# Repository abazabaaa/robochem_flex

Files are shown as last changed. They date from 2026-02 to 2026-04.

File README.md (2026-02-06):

NRG Logo

# Robochem-Flex

This repository bundles the **software, device files, and example data** for the  
**Robochem-Flex** platform: a modular self-driving laboratory framework.  

---

## 🔎 Repository Structure

- **Control Software**  
  Streamlit application and supporting backend code for configuring and running optimisation campaigns.

- **Devices**  
  Hardware resources such as CAD models, firmware, and PCB designs for the actuators and sensors used on the platform.

- **Examples**  
  Sample configuration files demonstrating how to set up a campaign and define stock solutions or vial layouts.

Each directory contains more detailed documentation specific to its contents.  
To run the platform optimization code, please refer to the README.md file within the Control Software folder.

---

## 🧑‍🔬 Authorship & Credits

The contents of this repository have been developed by:  

- **Dr. Simone Pilon** – University of Amsterdam, Noël Research Group
- **Ir. Elia Savino** – University of Amsterdam, Noël Research Group 
- **Dr. Oliver M. Bayley** – University of Amsterdam, Noël Research Group

for full credits on the project, please see the [accompanying publication](https://chemrxiv.org/doi/10.26434/chemrxiv-2025-73xqf).

If you use any part of this repository, please cite the accompanying publication.

---

## ⚖️ Licensing

The contents of this repository are licensed under the Apache License, Version 2.0.
For more information, consult the NOTICE and LICENSE files.

Copyright 2025 [Noël Research Group](https://www.noelresearchgroup.com).

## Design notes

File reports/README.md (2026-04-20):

# Reports Index

This directory contains ten cross-cutting reports that dissect the `robochem_flex` self-driving-lab codebase from the wire protocol up to the Bayesian-optimisation loop and the analytics feedback path. Each report is self-contained but cross-references the others; together they answer the question "how does this code control a robot, and how does it close the loop with machine learning?". File/line citations point into `Control Software/OmniPlatypus/…`, `Control Software/backend/…`, `Control Software/Lamas/…`, and `Devices/*/Firmware/*.ino`. Start here, then read in one of the two orders below. For a single-document synthesis, see `../REPO_MAP.md`.

## Contents

| # | Title | Purpose |
|---|---|---|
| 01 | Hardware Communication Layer | Dissects `BaseDevice`, the `ArduinoDevice`/`ModbusDevice`/`SocketDevice` transports, and the `ArrayDevice`/`ProxyDevice` pattern that lets many sub-units share one serial port. |
| 02 | Platform & Device Configuration | Explains `platform_config.json`, `Platform.build()`, `known_devices.json` serial-ID discovery, and `SampleHolder` vial-rack geometry. |
| 03 | Unit Task to Wire Trace | Follows `PumpVolume` and `SetLightSourceIntensity` all the way from Python down to the literal ASCII bytes on the serial wire and the matching firmware `case` handler. |
| 04 | Experiment Orchestration Lifecycle | Documents `BaseExperiment`'s threads, five queues, `RunResult`, and the `ChemicalReaction`/`PhotochemicalReaction`/`ThermochemicalReaction` subclasses. |
| 05 | ML - Hardware Closed Loop | Traces BoTorch backends, `ToandFromMachine` tensor/recipe translation, and the queue boundary between the ML thread and the experiment thread. |
| 06 | Sample Prep & Liquid Handling | Covers `StockSolutionDF`/`VialDF`, the `GenerateComposition` linear-programming recipe solver, and the pump/sampler unit tasks. |
| 07 | Analytics & Measurement Feedback | Walks raw spectra through Alpaca, Vicuna, Guanaco, and Lama; contrasts NMR/HPLC/Raman/UV-Vis analyser classes; defines the `result_metrics`/`pass` contract. |
| 08 | End-to-End CS1 Walkthrough | A single Bayesian iteration of the `Examples/CS1` photoredox campaign on platform Perry, from Start button to refitted GP posterior. |
| 09 | Arduino Firmware Protocol Reference | Per-device variable tables, the `Sx=y`/`Rx` line protocol at 9600 baud, ACK characters, and firmware safety interlocks. |
| 10 | Safety, Errors & Recovery | Error-class taxonomy, the three-tier retry/restart policy, known gaps including the missing hardware emergency-stop. |

## Read in this order

- **To understand how the code controls a robot** (bottom-up mechanics): start with **02** (platform configuration), then **01** (the `BaseDevice` abstraction), then **09** (what the firmware actually expects on the wire), then **03** (a worked wire-trace), then **08** (it all comes together).
- **To understand the ML loop** (top-down chemistry and learning): start with **05** (the optimizer and the queue boundary), then **06** (how a tensor becomes a real slug), then **07** (how a spectrum becomes a scalar), then **04** (the orchestrator that threads the two together), then **08** (a concrete campaign iteration).

Reports 09 and 10 are reference material — consult them on demand when the other reports cite specific firmware variables or error classes.

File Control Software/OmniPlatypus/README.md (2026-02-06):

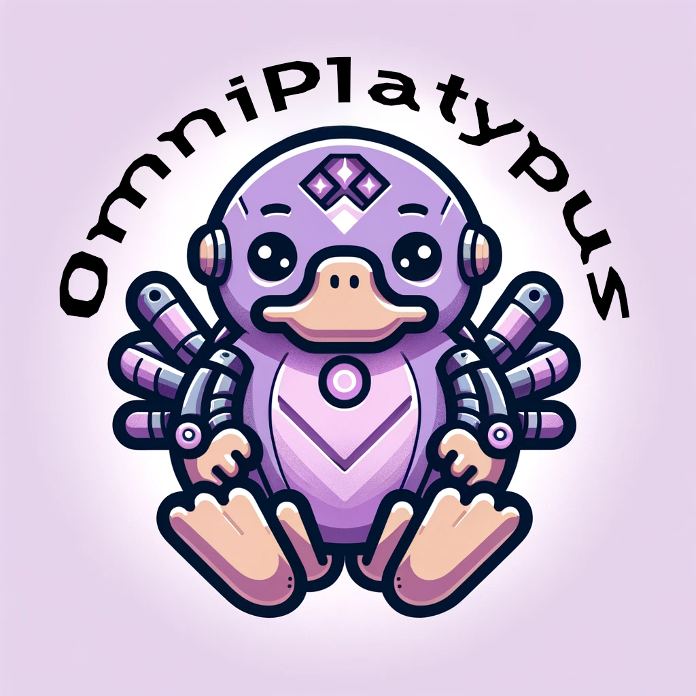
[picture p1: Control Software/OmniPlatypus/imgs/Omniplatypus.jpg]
Omniplatypus Logo
# OmniPlatypus

> ***"We're stuck with technology when what we really want is just stuff that works"***  
> — *Douglas Adams (The Salmon of Doubt) *

The **NRG's next-generation platform for Automated Chemistry**, providing a flexible, modular, and easily extendable framework to control, coordinate, and analyze complex experimental setups.

OmniPlatypus is designed for **atomic customizability**: every device, unit task, and experimental procedure can be configured, reused, or replaced independently. The platform supports seamless communication between analytical instruments, pumps, sensors, and other devices — enabling full workflow automation.

---

## Building the Package

If you’re unsure whether the local package is up to date, rebuild it manually.

From the directory containing the `setup.py` file, run:
```bash
python setup.py sdist bdist_wheel
```

Then uninstall and reinstall the package:
```bash
pip uninstall omniplatypus -y
pip install dist/omniplatypus-<version>.whl
```

---

## Installation

Install **OmniPlatypus** as an *editable package* (recommended for development and frequent updates).

### From the Command Line

1. Activate your environment (`conda activate omniplatypus_env`)
2. Locate the root path of the OmniPlatypus repository
3. Run:
   ```bash
   pip install -e <path-to-repo>/omniplatypus
   ```
4. The `-e` flag ensures your installation automatically reflects local changes.
5. Enjoy automating your chemistry.

---

### Within PyCharm

1. Open the **Python Packages** panel.
2. Click **Add Package → From Disk**.
3. Select the path:  
   `<path-to-repo>/OmniPlatypus`
4. Make sure **“Install as editable (-e)”** is checked.
5. Have fun experimenting.

---

## Project Structure

OmniPlatypus follows a clear, modular structure:

```
omniplatypus/
│
├── procedures/
│   ├── experiments/       # Full experimental workflows (e.g., photochemistry, thermochemistry)
│   ├── unit_tasks/        # Atomic operations: driving, sampling, measuring, sensing, reactor
│   └── analytics/         # Interfaces for analytical instruments (to be extended)
│
├── devices/               # Hardware-specific communication drivers (if present)
│
├── utils/                 # Shared utilities, configuration, and logging (optional)
│
└── __init__.py
```

### Core Concepts

More specific docs about all the below can be found in the dostring of each class.

#### Unit Tasks
Atomic building blocks that define low-level operations, implemented as **class factories** under:
```
procedures/unit_tasks/base_unit_task.py
```

Unit tasks include:
- **Driving** – pump and flow control (`driving_pumps.py`, `hplc_driving.py`)
- **Measuring** – analytical interfacing (`raman_spec.py`)
- **Sampling** – liquid handling and injection operations
- **Sensing** – optical/physical sensor integration (`phase_sensors.py`)
- **Reactor** – light and temperature control (`reactor/light.py`)

These tasks can be recombined to build complex experiments.

#### Experiments
Full workflow definitions found in:
```
procedures/experiments/
```
Examples include:
- `photochemistry.py` — photo-driven reaction sequences  
- `thermochemistry.py` — temperature-controlled processes  
- `chemistry.py` — general reaction orchestration  

Each experiment defines the logical combination of unit tasks into a cohesive experimental sequence.

#### Analytics
Modules (e.g. Raman spectroscopy, UV-Vis) define how analytical instruments communicate with the platform for data acquisition and interpretation.

---

## Philosophy

OmniPlatypus is built to support **"atomic automation"** — each element of an experiment (pump, sensor, analysis tool) is a self-contained, replaceable module.  
This allows:
- Rapid prototyping of new experimental workflows  
- Seamless scaling from single devices to fully automated laboratories  
- Consistent communication standards across heterogeneous instruments  

---

## Registering a serial device

Devices within the platform are automatically recognized from a list of known devices. Those connected via USB are recognized by comparing their hardware-id and a combination of other 
identifiers. Note that some USB devices do not have an hardware ID. If many such devices are present, it can be impossible for the module to correctly recognize different devices.
To add a device to the list, take the following steps:

1. Plug the USB device in, making sure you can easily identify it from a list (disconnect any other unknown device which might confuse you).
2. Launch the "add_serial_device.py" script from the project root via the command line:
	```bash
	conda activate robochem_flex
	cd <project root>\OmniPlatypus
	python OmniPlatypus\omniplatypus\scripts\add_serial_device.py
	```
3. Identify your device from the list and follow the instructions, the script will store as much information as possible about the device in order to recognize it later.
4. If the device is self-developed, you can add a custom identifier to it and register its value too. This can help in case of identical Arduino boards, but slows down the recognition process, as the serial connection must be opened to read the identifier, which requires a few seconds.

> [!note]
> All scripts within "OmniPlatypus\omniplatypus\scripts" must be run from the package root folder ("\<project root\>\OmniPlatypus").

## Defining an automation platform

Platforms configuration is defined within the "platform_config.json" file, which can be found in the "\<project root\>\OmniPlatypus\OmniPlatypus\omniplatypus\config\" folder.
Here, a list of devices is given for each platform which can be controlled. The desired platform is selected when setting up an experiment within the GUI.
See the provided platform_config file for a complete example, the overall file structure is given below.

```json
  "Platform 1": {
    "constants": {
      ...
    },
    "devices": {
      ...
    },
    "Gui_Specs": {
      ...
    }
  }.
  "Platform 2": {
    "constants": {
      ...
    },
    "devices": {
      ...
    },
    "Gui_Specs": {
      ...
    }
  },
  ...
```

Each platform defines constant values, which are retrieved at runtime but should not be easily changed by the user. They are grouped hierarchically depending on which stage of the
process they apply to and which combination of equipment.
Under 'devices', each module of the platform is listed under a name which will be used to identify it in the experiment. An example is given below.

```json
    "devices": {
      "Main_Pump_1": {
        "tags": [
          "liquid",
          "flow",
          "3w_valve"
        ],
        "class": "syringe_pump_nrg",
        "serial": {
          "known_device": "main_pump_op1"
        },
        "setup": {
          "syringe_volume": "10.0mL",
          "syringe_stepperml": "7755.0",
          "max_flowrate": 60.0,
          "valve": true,
          "reservoir_valve_position": "OFF",
          "aux-valve": true
        }
      },
      ...
   },

```

Under 'tags' the user can specify a number of keywords. These can be retrieved within the user code, but are otherwise ignored by the omniplatypus module.
Under 'class' a name specifying the correct interface class for this device must be given. Valid entries are listed in omniplatypus.devices.Platform.DEVICE_CONSTRUCTORS.
Under 'serial', the name given to the USB device must be provided, as defined when calling the 'add_serial_device' script. Alternatively, the keyword 'IP' is used as follows:
```json
        "IP": {
          "host": "192.168.1.202",
          "port": 99999
        }
```
if the device is meant to connect via a socket IP interface. Host and port must match the address that the device can be reached at from the controlling computer.
Under 'setup' a number of device parameters are set, such as the diameter of the syringe in a pump or the location of the vial holders within a sampler unit.
Information on the available setup options for each device is given in the "\<project root\>\OmniPlatypus\doc" folder.

## Testing

To run the test suite (if included):
```bash
python -m unittest OmniPlatypusTests
```

---

## Contributors

Developed within the **Noël Research Group** (NRG)  
*University of Amsterdam* — Department of Flow Chemistry

Main Contributors:
Simone Pilon
Elia Savino
Oliver Bayley

---

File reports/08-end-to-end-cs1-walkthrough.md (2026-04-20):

# 08 — End-to-End Walkthrough: CS1 Photoredox Campaign

This report stitches the layers of Robochem together by tracing a single Bayesian iteration of the `Examples/CS1` campaign — a photoredox catalyst/conditions screen on platform Perry — from the moment the user presses **Start** in the Streamlit UI to the moment a new `(x, y)` pair has been fed back into the GP posterior.

## 1. CS1 Session Snapshot

`Examples/CS1/session.json` defines the campaign:

- **Platform / experiment**: `"platform_name": "Perry"`, `"platform_experiment": "PhotochemicalReaction"`, `"experiment_type": "BO_optimisation"` (`session.json:4-7`).
- **Physical parameters**: `residence_time` variable 30–100000 s (`:8-16`), `light_intensity` variable 0–100 % (`:17-25`), constants `slug_volume = 600 uL` (`:26-34`) and `flowrate_sampling = 0.5 mL/min` (`:35-43`).
- **Chemical design space** (`StockDF`, `:46-64`): one SM (`"Internal_ID": SM`), five candidate catalysts (`Ru(bpy)Cl`, `Ru(bpy)PF6`, `Ir(ppy)`, `Ir(CF3)ppy`, `5CzBN`), one excess reagent (`TFAA`), two "other" reagents (`PyNO`, `4-PhPyNO`), solvent `MeCN`.
- **Analysis**: `"analysis_type": "NMR"`, target peak at `-57.94 ppm` with `simple_integration`, calibration slope `target_peak_calibration_coeff_1 = 1654.9 mM/AU` (`:457-754`). (Despite the NMR analytical tag, CS1's live readout on Perry runs through the Raman backend — see §7.)
- **ML parameters** (`:756-989`): `Limiting Reagent_ml` 100–200 mM (single-discrete "SM"); `Catalyst_ml` 0.001–0.004 eq across five discrete catalysts with a learned 3-D embedding; `Excess Reagent_ml` 0.9–3.5 eq of TFAA; `Other Reagent_ml` 0.9–3.0 eq across `[PyNO, 4-PhPyNO]` with 1-D embedding; `residence_time_ml` 120–1800 s continuous; `light_intensity_ml` 0–100 % continuous.
- **Objectives**: `["yield", "residence_time"]` with `weights = [0.9, -0.1]` (`:991-1016`).
- **BO backend** (`:995-1017`): `SingleBayesianOpti` → `SingleTaskGP` + `UCB` acquisition, `LHS` init (15 points), 50 total iterations, batch size 1, adaptive exploration (`Explorative Factor = 10.0`), `Resubmission of Failed N = 1`.
- **Vial map** (`VialDF.csv`): 17 stock/solvent/wash vials on `Sampler_cnc` + 36 sample vials on `Collector_cnc`. Relevant stocks sit in `holder_D`: `Stock_SM` at `D/A1` @ 1000 mM (`VialDF.csv:2`, `StockSolutionDF.csv:2`), `Stock_TFAA` at `D/B2` @ 3500 mM (`VialDF.csv:10`, `StockSolutionDF.csv:8`), `Stock_Irppy` at `D/C3` @ 3 mM (`VialDF.csv:13`, `StockSolutionDF.csv:5`), `Stock_PyNO` at `D/A2` @ 2000 mM (`VialDF.csv:17`, `StockSolutionDF.csv:9`).

## 2. Clicking "Start"

`pages/07_Run_Platform.py:117-122` binds the **Start** button to `backend.start` on the singleton `PlatformBackend`. That handler (`platform_backend.py:746-762`) does three things:

1. `initialise_platform()` (`:693`) instantiates `PhotochemicalReaction` via `self.platform_constructors[experiment_key]` and calls `platform_experiment.start(...)` which opens serial ports to all Arduinos, runs the optional startup cleaning, and launches the experiment's background run loop.
2. `initialise_ML()` (`:496-571`) gathers the ML-tagged parameters and constants out of `session_container`, runs `ml_experiment_class.ML_prime(...)` then `com_prime(experiment=self.platform_experiment, parameter_machine=self.parameter_machine)` (`:554-565`) to wire the BO backend to the physical coupler, then `ml_experiment_class.run()` spawns the proposer thread.
3. `self._rolling.set()` flips the shared `Event` that `07_Run_Platform.py:137` polls to swap the UI into live-results mode (`main_results()`, `save_periodically()`).

## 3. The BO Backend Proposes

Because `session.json` names `SingleBayesianOpti`, `ml_backends.py:850` resolves to `SingleBayesianOpti(ML_Platform_omni, SingleBayesianOptiBackend)`. With 15 LHS seed points complete, iteration #16 enters BO mode: the backend fits a `SingleTaskGP` on `(x_normalized, y_weighted)` for the two weighted objectives, builds a `UCB` acquisition with `beta` scaled by the adaptive explorative factor (`Explorative Factor = 10.0`, thresholds `0.05/0.8`, counter `3`) and optimises it over the mixed space:

- 1 continuous dim for `residence_time`
- 1 continuous dim for `light_intensity`
- 1 continuous dim for `[SM]`
- 1 continuous + 3-D embedding for catalyst choice
- 1 continuous for `[TFAA]`
- 1 continuous + 1-D embedding for `PyNO/4-PhPyNO` choice

The optimiser emits a single candidate `tensor` which is handed to `ToandFromMachine._to_machine` (`ml_backends.py:47-250`). Each `ML_parameter` is inverse-transformed: `back_translation_continuous` returns unitful floats (e.g. 1450 s, 75 %, 150 mM, 2.1 eq) while `back_translation_discrete` on the catalyst and "other reagent" embeddings picks the nearest discrete label (e.g. `Ir(ppy)`, `PyNO`). The output is a list of typed parameters — `ChemicalParameter(name="Ir(ppy)", value=0.00225, units="eq", foreign_key="Catalyst")`, `NumericalParameter(name="residence_time", value=1450, units="S")`, etc. — with `sampling_priority` tags pulled from `_sampling_priorities` (`:53-73`, e.g. `Limiting Reagent → 50000`, `Catalyst → 10000`). Analytical constants (`target_peak = -57.94 ppm`, `yield_calculation_chemical = "SM"`) are appended from `constants` (`:186-250`). The resulting recipe+conditions bundle is pushed into the `platform_experiment` run queue.

## 4. Recipe Construction — a Concrete CS1 Slug

Inside the experiment thread, `ChemicalReaction._procedure_experiment` (`chemistry.py:716-724`) calls `GenerateComposition.run(platform, experiment_recipe, slug_volume=600.0 uL, sampler_name="Sampler_cnc")` (`liquid_handler_sampling.py:1069-1144`). The task walks `platform.samples` (seeded from `VialDF.csv`) and for each `RecipeComponent` picks the least-full `Stock` vial whose `Conc_<name>` column has the compound, then solves `C_stock * V_extract = C_target * 600 uL` per ingredient.

For the candidate above (`[SM]=150 mM`, `[TFAA]=2.4·150=360 mM`, `[Ir(ppy)]=0.00225·150=0.338 mM`, `[PyNO]=2.1·150=315 mM`, MeCN to balance), and using the CS1 stocks from `StockSolutionDF.csv`:

| Component | Stock (conc) | Vial (Sampler/Holder/Pos) | Volume (µL) |
|---|---|---|---|
| SM @ 150 mM | Stock_SM (1000 mM) | Sampler_cnc/holder_D/A1 | 90.0 |
| TFAA @ 360 mM | Stock_TFAA (3500 mM) | Sampler_cnc/holder_D/B2 | 61.7 |
| Ir(ppy) @ 0.338 mM | Stock_Irppy (3 mM) | Sampler_cnc/holder_D/C3 | 67.6 |
| PyNO @ 315 mM | Stock_PyNO (2000 mM) | Sampler_cnc/holder_D/A2 | 94.5 |
| MeCN solvent | sol_MeCN_1 | Sampler_cnc/holder_F/B1 | 286.2 |
| **Slug total** | | | **600.0** |

`GenerateComposition` returns `(sampler_recipe: list[VialRecipeComponent], recipe)`; `OrderRecipe.run` (`photochemistry.py:231-233`) then orders the list by `sampling_priority` (SM first, other reagent next, excess, catalyst, solvent last).

## 5. Physical Execution — One Slug on Perry

Photochemistry triggers `_reactor_prepare` (`photochemistry.py:111-125`) before the slug leaves the sampler, invoking `SetLightSourceIntensity.run(source=uflow_kessil, intensity=75)` (rounded to the nearest 25 %) via `unit_tasks/reactor/light.py:13-22`. The `ChemicalReaction` parent then walks the slug through (`chemistry.py:742-849`):

- **Gas dry + tail bubble** — `MixSlugSampler.run(sampler=Sampler_cnc, amplitude=..., flowrate=gas_purging_flowrate, cycles=gas_purging_cycles, margin_bottom=slug_tail_bubble_volume)` (`chemistry.py:745`, `liquid_handler_sampling.py:2674`).
- **Empty sampler syringe** — `FillPump.run(pump=sampler_pump, fill=False)` (`driving_pumps.py:367`).
- **Aspirate ingredients into sampling loop** — `PrepareReactionSlug.run(platform, recipe=sampler_recipe, sampling_flowrate=0.5 mL/min, bubble_between_components=...)` visits each vial in priority order, moving `Sampler_cnc` Cartesian head over `holder_D/A1`, `D/A2`, `D/B2`, `D/C3`, `holder_F/B1` and withdrawing the 90/94.5/61.7/67.6/286.2 µL computed above (`chemistry.py:783-793`, `liquid_handler_sampling.py:2366-2378`).
- **Pre-injection mix** — `MixSlugSampler.run(...)` at `mix_before_injection_flowrate` for `mix_before_injection_cycles` (`chemistry.py:799-811`).
- **Refill and inject** — `FillPump.run(fill=True)` (`driving_pumps.py:367`) then `Inject.run(sampler=Sampler_cnc, injection_port_name="injection_flow", volume=slug+head+tail+port, flowrate=flowrate_injection, sampling_pump=sampler_pump, retract=True)` (`chemistry.py:836-848`, `liquid_handler_sampling.py:2001`).
- **Push to mixing chamber + in-reactor mix** — `PumpVolume.run(pump=main_pump, volume=injection_to_mixing_volume, flowrate=flowrate_delivery)` (`driving_pumps.py:490-536`), then optional `MixSlug.run(pump=main_pump, amplitude, flowrate, cycles)` (`driving_pumps.py:721-731`).
- **Drive through the photoreactor at the BO residence time** — `PumpVolume.run(pump=main_pump, volume=reactor_volume, flowrate=reactor_volume / residence_time)`. Kessil remains at 75 % for the full pass.
- **Phase-sensor gate at reactor exit** — `PumpUntilPhaseChange.run(pump=main_pump, sensor=phase_sensor_out, flowrate=flowrate_slug_check, ...)` (`sensing/phase_sensors.py:303-415`) advances until the leading bubble is detected, ensuring the slug front arrives at the measurement cell before Raman fires.
- **Raman acquisition** — `SetRamanParameters.run(...)`, `StartAcquisition.run(spectrometer=rama_berry)`, wait `integration_time × n_averages + delay`, `StopAcquisition.run(...)`, `GetRamanData.run(...)` (`measuring/raman_spec.py:38,86,104,122`). The result goes into `RunResult` and a fraction is collected to the Collector vial via `PumpSample.run(...)` (`liquid_handler_sampling.py:1636-1662`).
- **Reactor standby** — `SetLightSourceIntensity.run(source=uflow_kessil, intensity=0)` (`photochemistry.py:150`).

## 6. Wire-Level Handoffs

- **Pump strokes** (`FillPump`, `PumpVolume`, `MixSlug`, `PumpSample`, `Inject`): the `liquid_handler_sampler` / `main_pump` drivers serialise G-code-style motion commands over USB-serial to the Trinamic/AccelStepper sketch in `Devices/Syringe Pump/Firmware/syringe_pump_nrg/` which drives the lead-screw stepper and reads the home/end endstops.
- **`SetLightSourceIntensity`**: the `Light_Array` device writes a PWM duty (0/25/50/75/100 %) to `Devices/Photochemical Reactor Controller/Firmware/Lights_Array/` which controls the Kessil uFlow driver and simultaneously exposes a current sense line that `ContinuousMonitoring` polls every 30 s (`photochemistry.py:97-109`).
- **`PumpUntilPhaseChange` / `MonitorPhase`**: `FC_cnc`'s optical phase-sensor bank is implemented by `Devices/Phase Sensor Controller/Firmware/Phase_Sensor_Array/`, which streams per-channel intensity readings that `sensing/phase_sensors.py:415` polls in a tight loop while commanding the pump step.

## 7. Measurement → LAMAS → BO Feedback

`AnalyticsRaman.analyse` (`raman_analysis.py:222-292`) sets spectrometer parameters, calls `_spectrometer_run` (talks to the Raman host script in `Devices/Raman Spectrometer/Spectrometer Control/`), then hands the acquired spectrum to `_process_analytics` (`:453-488`). The configured `processing_function` (`isosbestic_integral`) is the LAMAS peak-resolver: it deconvolves the SM and product bands around the isosbestic point and returns `{PI_conc, SM_conc, PI_area, SM_area, PI_var, SM_var}`. `_make_results` (`:490-651`) sets `yield = pi_conc` (i.e. product concentration against the recipe's SM ref; `:560`), attaches `yield_variance`, and returns a `RunResult`.

Control hops back to the ML side: `ToandFromMachine._from_machine(results)` (`ml_backends.py:276-355`) unpacks `results.result` → metrics dict, zips the target vector `y = [yield, residence_time]` and `y_var`, and walks `results.parameters` to rebuild the `x` tensor using `translation_continuous` / `translation_discrete` for each `ML_parameter`. The `(run_index, x, y, y_var, vial_idx, save_file_name)` tuple is appended to the BO backend's training set, the GP posterior is refit with the new point, and the adaptivity counter ticks — if the last three UCB improvements stayed below `adaptive_threshold_exploration = 0.05`, the explorative factor dilates on the next proposal. The frontend observes the new row via `frontend_queue` and `main_results()` redraws the hypervolume and objectives plots.

## Sequence Diagram

```mermaid
sequenceDiagram
    participant U as User
    participant UI as 07_Run_Platform.py
    participant PB as PlatformBackend
    participant ML as SingleBayesianOpti
    participant T2M as ToandFromMachine
    participant EX as PhotochemicalReaction
    participant GC as GenerateComposition
    participant HW as Unit Tasks + Firmware
    participant AN as AnalyticsRaman + LAMAS

    U->>UI: Click Start
    UI->>PB: backend.start()
    PB->>EX: initialise_platform() → start()
    PB->>ML: initialise_ML() → ML_prime + com_prime + run()
    PB-->>UI: _rolling.set()
    ML->>ML: Fit SingleTaskGP, optimise UCB
    ML->>T2M: candidate tensor
    T2M-->>EX: recipe + conditions (ChemicalParameter, NumericalParameter, AnalyticalParameter)
    EX->>GC: GenerateComposition.run(slug=600 uL)
    GC-->>EX: sampler_recipe (vial_id → volume)
    EX->>HW: SetLightSourceIntensity(75%) [Lights_Array FW]
    EX->>HW: PrepareReactionSlug → Inject → PumpVolume [Syringe Pump FW]
    HW->>HW: PumpUntilPhaseChange [Phase_Sensor_Array FW]
    EX->>AN: StartAcquisition → GetRamanData
    AN->>AN: isosbestic_integral → PI_conc, SM_conc
    AN-->>EX: RunResult(yield, yield_variance, ...)
    EX-->>T2M: RunResult
    T2M->>ML: _from_machine → (x, y, y_var)
    ML->>ML: Refit GP, update adaptivity
    ML-->>UI: frontend_queue → main_results()
```

---

**Summary**: CS1's `session.json` declares a 6-parameter UCB Bayesian loop on Perry with weighted objectives `[yield 0.9, residence_time -0.1]`; pressing Start chains `initialise_platform → initialise_ML → _rolling.set`, after which `SingleBayesianOpti` proposes a tensor that `ToandFromMachine._to_machine` renders into a typed recipe, `GenerateComposition` converts into per-vial µL volumes against the CS1 stock and vial CSVs, and the photochemistry experiment drives the slug through ordered sampler, pump, light, phase-sensor and Raman unit tasks (each backed by a specific Arduino firmware in `Devices/`). `AnalyticsRaman.analyse` runs the LAMAS `isosbestic_integral` processor, yielding `(PI_conc, SM_conc, variances)` that become the `yield` scalar, which `_from_machine` converts into `(x, y)` and feeds back into the GP posterior for the next iteration.

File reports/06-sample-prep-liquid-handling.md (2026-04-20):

# 06 — Sample Prep & Liquid-Handling Automation

This report covers how a declarative slug recipe ("0.15 mM Ru(bpy)Cl photocatalyst + 500 mM SM in MeCN") is turned into the ordered sequence of pump fills, sampler moves, and injections that physically produce the reaction slug. The two central artefacts are the `StockSolutionDF` / `VialDF` tables (what liquids exist and where) and the `GenerateComposition` unit task (a linear program that picks stock volumes to hit target concentrations).

Code paths are quoted relative to the repo root. Unit-task source lives under `Control Software/OmniPlatypus/OmniPlatypus/omniplatypus/procedures/unit_tasks/` — this doc uses the shorthand `unit_tasks/…` for brevity.

## 1. Data model: `StockSolutionDF` and `VialDF`

The system keeps two user-editable tables that together describe the liquid inventory of a campaign.

**`StockSolutionDF`** (`Control Software/backend/Robochem_ML/robrains/parameter_backends/stocksolutiondf.py:16`) is a wide-format DataFrame with one row per stock bottle and one column per chemical. Its columns for CS1 (`Examples/CS1/StockSolutionDF.csv`) are:

```
StockID, Solvent, Conc_SM, Conc_Ru(bpy)Cl, Conc_Ru(bpy)PF6, Conc_Ir(ppy), …
Stock_SM,     MeCN, 1000, 0, 0, 0, …     # 1 M SM in MeCN
Stock_RuCl,   MeCN,    0, 3, 0, 0, …     # 3 mM Ru(bpy)Cl in MeCN
Stock_IrCF3,  MeCN,    0, 0, 0, 0, 3, …  # 3 mM Ir(CF3)ppy in MeCN
Stock_TFAA,   MeCN,    0, 0, 0, 0, 0, 0, 3500, …  # 3.5 M TFAA
```

Concentrations are in **mM** (see `RecipeComponent.concentration_units`, `unit_tasks/sampling/liquid_handler_sampling.py:939`). The column convention `Conc_<chemical_name>` is critical: `GenerateComposition.chemical_to_column` (`…:1147`) maps recipe component names directly to DataFrame columns.

**`VialDF`** (`…/robrains/parameter_backends/vialdf.py`) is the *physical* inventory. CS1 (`Examples/CS1/VialDF.csv`) opens with:

```
VialID, VialName,       StockID,      Volume, Sampler,      Holder,   Position, Type,     Counter, Viable
0x001,  SM,             Stock_SM,     4000,   Sampler_cnc,  holder_D, A1,       Stock,    0,       TRUE
0x003,  sol_MeCN_1,     MeCN,         10000,  Sampler_cnc,  holder_F, B1,       Solvent,  0,       TRUE
0x005,  wash_MeCN_1,    Not a Stock,  10000,  Sampler_cnc,  holder_F, A1,       Cleaning, 0,       TRUE
0x007,  N2,             Not a Stock,  0,      Sampler_cnc,  holder_A, D1,       Gas,      0,       TRUE
0x008,  Mixing,         Not a Stock,  0,      Sampler_cnc,  holder_A, D2,       Mixing,   0,       TRUE
```

Each physical vial therefore carries: a unique `VialID`, the `StockID` it was filled from (inherited concentration profile), remaining `Volume` in µL, its `Sampler`/`Holder`/`Position` (physical coordinates), a `Type` that drives task filtering (`Stock`, `Solvent`, `Cleaning`, `Gas`, `Mixing`, `Waste`, `Reaction`…), and a `Viable` flag that the orchestrator toggles off when a vial has been exhausted.

At platform startup, `GenerateSampleDataframe` (`unit_tasks/sampling/liquid_handler_sampling.py:292`) joins the `VialDF` with the `StockSolutionDF` to produce a per-vial concentration profile plus physical `X`,`Y` coordinates (resolved from the sampler's `setup.locations` + the holder geometry). The resulting table is stored on the platform as `platform.samples` and is the sole DataFrame that downstream tasks read — there is no direct access to `VialDF`/`StockSolutionDF` from the run loop.

## 2. Recipe composition: `GenerateComposition` (the LP solver)

`GenerateComposition` (`unit_tasks/sampling/liquid_handler_sampling.py:1069`) is the heart of sample prep. Its signature (`:1088`) is:

```python
GenerateComposition.run(
    platform,
    experiment_recipe: list[RecipeComponent],   # target chemicals + concentrations in mM
    slug_volume: float,                          # µL
    sampler_name: str,
    max_relative_error: float = 0.05,
    min_volume: float = 0.5,                     # µL — drop-ingredient threshold
    min_accurate_volume: float = 20.0,           # µL — retry-with-alternative-stock threshold
) -> tuple[list[VialRecipeComponent], list[RecipeComponent]]
```

The comment block at `:1348–1395` lays out the LP directly:

> `Ax + s = C`, where **A** is the concentrations-in-vials matrix (rows = unique stock profiles, cols = compounds), **C** is the desired moles vector (`target_concentration × slug_volume`), **x** is the unknown per-stock-vial volume. The objective minimizes `Σ x_i` (total solvent/stock volume used).

The actual call is SciPy's HiGHS LP:

```python
opt = linprog(
    c=objective,          # np.ones(n_vials) — minimize total volume
    A_ub=-A.T,            # -A_ij ≤ -C_j  ⇔  Σ_i A_ij x_i ≥ C_j  (concentration floor)
    b_ub=-moles_vector_c,
    bounds=bnd,           # per-vial volume bounds from _calculate_bounds
    method="highs",
)
```

Quality gates after the solve (`:1396–1423`):

1. Each volume is **rounded** to the precision implied by `min_volume` (`round_to_digits = -⌊log₁₀(min_volume)⌋`). For CS1's default `min_volume=0.5 µL` this means rounding to the nearest 0.5 µL — enforcing that the recipe respects the syringe's actual dispensable resolution.
2. Back-computed concentrations are compared against targets; any compound whose relative error exceeds `max_relative_error` (5 % default) triggers a `RecipeError` with a per-compound note. The error propagates up to the experiment loop, where `BaseExperiment._run` catches it as a skippable iteration rather than a halt (see report 10).
3. If an ingredient needs `< min_accurate_volume` (20 µL) the code searches for an alternative lower-concentration stock that would push the required volume into the accurate range (recursive retry via `stashed_recipies`, excluding the first-choice vial).

The output is a `list[VialRecipeComponent]` — one entry per physical vial that will be sampled, each with `vial_id`, `volume_uL`, and `sampling_priority` — plus the adjusted `RecipeComponent` list whose concentrations reflect the rounding.

## 3. Scheduling: `FindVial` and `OrderRecipe`

`FindVial` (`unit_tasks/sampling/liquid_handler_sampling.py:725`) is the point-lookup: "closest viable vial of type X that has room for Y µL". It consults `platform.samples`, filters by `Type`, `Viable`, and (optionally) volume-after-operation, then orders candidates by Euclidean distance from either the sampler's current position or a reference sample's position. If no candidate is found and `allow_user_requests=True`, it enqueues a `UserActionRequest` on the experiment's `_action_request_queue` (see report 04); the user must load a fresh vial before the task resolves. Otherwise it raises `NoSuitableVialError` (`unit_tasks/errors.py`), which the experiment loop can either propagate or skip depending on context.

`OrderRecipe` (`:2180`) takes the `VialRecipeComponent` list from `GenerateComposition` and reorders it for the actual dispense: high-priority components (tagged by `RecipeComponent.sampling_priority`, default `1000`) are drawn first so they don't sit in the needle or slug while slower dilutions are prepared. Distance-aware ordering also reduces needle travel.

## 4. Pump actions — the driving side

`unit_tasks/driving/driving_pumps.py` defines four tasks that operate on a `SyringePump` device:

| Class | Lines | Purpose |
|---|---|---|
| `PrimePump` | `:231` | Flush pump + lines with a wash solvent before use. Typically runs once per campaign, not per slug. |
| `FillPump` | `:367` | Draw `volume` µL from a specified vial into the barrel. Called once per unique stock-vial component of the recipe. |
| `PumpVolume` | `:490` | Push a specified volume out of the barrel (downstream to reactor or waste). This is the canonical dispense — see report 03 for the wire trace: host emits `S9=<uL>\n`, firmware acks `'k'`. |
| `MixSlug` | `:721` | Oscillate the plunger to mix the contents of the barrel before dispensing — used when multiple stocks were drawn in sequence to homogenise the slug. |

Every task inherits from `PumpTask` (`:24`), which in turn extends `BaseUnitTaskTemplate` from `unit_tasks/base_unit_task.py`. The `validate → execute → cleanup` contract there ensures a failing pump operation is wrapped as `TaskTimeoutError` or `DeviceCommunicationError` (report 10) rather than leaking `pyserial` exceptions.

## 5. Sampler actions — the moving/injecting side

Two sibling files handle the XY(Z) Cartesian sampler:

- **`unit_tasks/sampling/liquid_handler_moving.py`** — `SamplerTask` (`:16`) is the sampler-aware base. `HomeSampler` (`:188`) homes the gantry; generic movement lives in other `SamplerTask` subclasses invoked internally when `Inject` / `ConnectInjectionPort` need to reach a vial.
- **`unit_tasks/sampling/liquid_handler_injecting.py`** — `ConnectInjectionPort` (`:166`) couples the needle to a vial's septum; `Inject` (`:228`) performs the actual piercing/aspiration/dispense at a vial. Both are where the abstract `VialRecipeComponent` meets the physical vial — they consume a `VialID`, resolve its `(Holder, Position)` → `(X, Y)` via `platform.samples`, drive the sampler, then delegate to the syringe pump for the actual fluid motion.

Under the hood the CNC sampler used by CS1 is `Sampler_cnc` — a Cartesian Arduino-driven device whose firmware is documented in report 09. Its coordinate origin and per-holder offsets come from the platform config's `sampler.setup.locations` block (report 02).

## 6. Worked example: one CS1 slug

Suppose the BO backend proposes one experimental point that asks for **0.15 mM Ir(CF3)ppy**, **500 mM SM**, **50 mM TFAA**, **500 µL slug** in MeCN. The flow (conceptual — the real numbers depend on the solve):

1. **Recipe construction.** `ToandFromMachine._to_machine` (report 05) converts the ML tensor into three `RecipeComponent`s. The experiment calls `GenerateComposition.run(platform, recipe, slug_volume=500, sampler_name="Sampler_cnc")`.
2. **LP solve.** The unique stock profiles considered are `Stock_SM (SM=1000)`, `Stock_IrCF3 (Ir(CF3)ppy=3)`, `Stock_TFAA (TFAA=3500)`, plus solvent. Target moles in 500 µL are `SM: 0.5·500·1e-3=0.25 µmol`, `Ir(CF3)ppy: 0.075 µmol`, `TFAA: 25 µmol`. HiGHS returns approximately:
   - Stock_SM:    **250 µL** (gives 1000 mM × 250 µL = 250 nmol → 500 mM in 500 µL ✓)
   - Stock_IrCF3: **25 µL**  (3 mM × 25 µL = 75 nmol → 0.15 mM in 500 µL ✓)
   - Stock_TFAA:  **7.5 µL** — **below `min_accurate_volume=20 µL`**, triggering the alternative-stock retry. With no alternative TFAA stock defined in CS1's inventory, the code falls through and keeps the 7.5 µL value (rounded to the nearest 0.5 µL) with a logged warning.
   - Pure MeCN (from `Stock_MeCN` or a `Solvent`-type vial): **217.5 µL** as makeup.
3. **Vial scheduling.** `FindVial` is called per stock: it returns `0x001 (Stock_SM, holder_D A1)`, the nearest viable Ir(CF3)ppy stock, etc. `OrderRecipe` emits them in descending sampling priority so SM (bulk) goes last and catalyst (trace) goes first, minimising cross-contamination risk.
4. **Physical execution.** For each entry the experiment executes `SamplerTask` → move to vial → `ConnectInjectionPort` → `FillPump(volume=X)` to draw that stock into the barrel; repeat; then `MixSlug` to homogenise the 500 µL slug; then a `SamplerTask` move to the injection port of the reactor, followed by `PumpVolume(500)` to push the whole slug into the photoreactor at the proposed flow rate. The gas-segmented phase sensor (report 09) gates the downstream analytical step.
5. **Bookkeeping.** Each `FillPump` decrements the corresponding vial's `Volume` column in `platform.samples` by the drawn amount; when a vial drops below the next task's required volume, `FindVial` transparently switches to the next parallel vial (e.g. `0x002 SM2` for the SM reservoir). The experiment loop only sees `RecipeError` or `NoSuitableVialError` if the whole inventory is exhausted.

## 7. Summary

The sampling stack is **declarative at the top and procedural at the bottom**: the user writes a chemistry recipe in `mM`/`µL`, an LP picks physical stock volumes that satisfy it within equipment-accuracy constraints, and a Cartesian sampler + syringe pump execute the draws in a priority-aware order. The two DataFrames (`StockSolutionDF`, `VialDF`) are the single source of truth for the liquid world, and their joined `platform.samples` view is the only structure the runtime queries — which makes the whole system largely decoupled from the specific robot: any Cartesian sampler + syringe pump that implements the respective device APIs can be dropped in without touching the LP or scheduler.

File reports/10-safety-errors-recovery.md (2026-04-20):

# 10 — Safety, Error Handling & Recovery

The Robochem Flex platform layers error handling across four tiers: firmware (endstops + error registers), serial-driver (timeouts + ack parsing), unit-task (domain exceptions), and experiment orchestrator (three-tier policy). Observability is via file logs plus a WebSocket stream. This report walks through what actually happens when things go wrong on the robot-control side.

## 1. Error taxonomy

The codebase splits exceptions into two hierarchies: one for physical devices (`devices/errors.py`) and one for procedural unit tasks (`procedures/unit_tasks/errors.py`).

| Exception | Base | Meaning | Raised in |
| --- | --- | --- | --- |
| `DeviceCommunicationError` | `DeviceError` | Serial open/read/write failed, or invalid device response | `device_arduino.py:470, 720, 773`; `open/close/_read/_write` |
| `NoResponseError`, `InvalidResponseError`, `FailedWriteError` | `DeviceCommunicationError` | Specialisations | `devices/errors.py:50–58` |
| `DeviceTimeoutError` | `DeviceError` | Top-level device op did not complete in time | `phase_sensors.py:152, 403, 820` |
| `ParameterTimeoutError` | `ParameterError` | Parameter ack not received in window | `device_arduino.py:667` |
| `ParameterAcknowledgeError` | `ParameterError` | Ack value malformed / unexpected | `device_arduino.py:691` |
| `ParameterCommError` | `ParameterError` | Unexpected serial data while servicing a parameter | `device_arduino.py:627` |
| `SoftLimitError` / `HardLimitError` / `AlarmLockError` | `ParameterError` | grblr (Cartesian sampler) alarms | `devices/nrg/sampler.py:1181, 1189, 1197` |
| `TaskTimeoutError` | `UnitTaskError` | Unit task did not hit its expected signal | `driving/driving_pumps.py:527` |
| `BadSlugQualityError` | `UnitTaskError` | Phase analysis failed: volume off-target | `sensing/phase_sensors.py:586` |
| `CloggingError` | `UnitTaskError` | Too few phase changes — possible blockage | `experiments/chemistry.py:911` |
| `NoSuitableVialError` | `UnitTaskError` | No vial matching type/volume constraints | `sampling/liquid_handler_sampling.py:840–2805` |
| `RecipeError` | `UnitTaskError` | Cannot compose a recipe from available stocks | `sampling/liquid_handler_sampling.py:1412, 1521, 1568` |

## 2. Hardware disconnect — `device_arduino.py`

`ArduinoDevice.open()` sets `_serial_iface.timeout = 1` and `write_timeout = 1` (`device_arduino.py:420–421`). On open it performs a 2 s sleep to ride out the Arduino auto-reset (`:466`). Every `_read`/`_write` operation wraps the underlying `pyserial` call in a try/except that catches `serial.SerialException, ValueError` and re-raises as `DeviceCommunicationError` carrying a reference to the originating device (`:719–724`, `:772–777`). The serial access itself is guarded by `self._serial_thread_lock` (`:710, 765`), so a disconnect never corrupts a concurrent reader.

There is no automatic reconnect inside the driver: `reopen()` exists (`:476–485`) but must be called explicitly. In practice, the reconnect is driven by the experiment's "restart-platform" tier (section below) — the caught `DeviceCommunicationError` bubbles up through the unit task and is caught in `BaseExperiment._run` (`base_experiment.py:837`). `flush_buffer_in()` (`:521`) is called before each transaction to drain stale data and trigger `parse_error()` on unexpected bytes, preventing a phantom response from being mis-parsed as an ack.

## 3. Hard limits — firmware vs Python

Hard limits are enforced *in firmware*, surfaced as *errors* over serial, and *translated* to Python exceptions.

Firmware side: the syringe-pump `AsyncStepperDriver` polls two endstop pins (`AsyncStepper.cpp:202, 234`) and writes `MOTOR_ERROR_ENDSTOP_POS`, `MOTOR_ERROR_ENDSTOP_NEG`, or `MOTOR_ERROR_BLOCKED` (motor stalled against no signal) into `last_error` (`AsyncStepper.h:40–45`). Main loop lifts this into the device-wide `error_type = ERROR_PUMP_MOTOR` register (`syringe_pump_nrg.ino:541–545, 593–596`). The register is polled by the Python side after every write (`device_arduino._verify_error_register`, `:731–749`) and translated to a `DeviceCommunicationError` via the `ArduinoError.exception()` lookup (`:199–229`).

For the grblr-based Cartesian sampler the firmware emits human-readable ALARMs (`"ALARM: Soft limit"`, `"ALARM: Hard limit"`, `"error: Alarm lock"`) which `sampler.py:1180–1204` converts into `SoftLimitError` / `HardLimitError` / `AlarmLockError`. Note: **there is no redundant Python-side range check** — the code trusts firmware enforcement.

## 4. Watchdog & continuous monitoring

`ContinuousMonitoring` (`unit_tasks/sensing/monitoring.py:173–234`) is a task designed to run on its own thread. It holds a list of `MonitoredValue`s, each with a `deque` history and a list of `MonitorEventTrigger` conditions. Every `update_delay` seconds (default 30 s) it reads each value and evaluates the triggers; if a condition fires, its `_on_true: Event` is set, which the main thread can wait on. A stability-check factory `stable_within_range` (`:76–102`) is provided. Exceptions during updates are logged but **do not abort the monitor** (`:233–234` — `cls.log(error, level="warning")`).

Phase sensors provide the other mid-run abort path. `WaitForPhaseChange._execute_wait` (`phase_sensors.py:69–157`) times out after a configurable window and raises `DeviceTimeoutError`; `PumpUntilPhaseChange._execute` raises it if the max volume is reached before phase change (`:403`). `SlugQualityCheck._execute` raises `DeviceTimeoutError` on timeout (`:820`) and `SlugQuality.raise_exception` raises `BadSlugQualityError` when the measured slug volume deviates beyond `max_volume_deviation` (`:586, 746`).

## 5. Emergency stop — Run Platform page

Looking at `Control Software/pages/07_Run_Platform.py:116–134`: the layout allocates four columns including one explicitly named `col_emergency_stop` (`:116`), but **only three buttons are actually created** — Start (`:117`), a commented-out Pause (`:123`), and "Shutdown" (`:129`). There is no wired-up emergency-stop button; the shutdown button is the strongest control surface.

"Shutdown" calls `experiment_shutdown()` (`:92–102`), which calls `backend.stop()`. `platform_backend.stop()` (`platform_backend.py:772–782`) performs three things: clears `self._rolling` (UI state), sets `self._emergency_stop` (an `Event`, `:133`), and calls `self.platform_experiment.stop()`. The last call (`base_experiment.stop`, `:336–353`) sets `_stop_event` and blocks on `_samples_queue`. Crucially, the running run is **allowed to complete** — stop_event is only checked at the top of the run-processing loop (`base_experiment.py:769, 792`). There is no mechanism to interrupt an in-flight device operation; true emergency-off requires the physical power switches mentioned in the on-screen checklist (`07_Run_Platform.py:70`).

## 6. Recipe / slug failures

`BadSlugQualityError`: caught in `chemistry.py:908`. If the failure was due to too few phase changes (`len(slug_shape.volumes) <= 1`) the handler escalates to `CloggingError` (`:911`), which is *not* in the retry list in `base_experiment.py:837` and will therefore halt the platform. Otherwise, the slug is flagged for discard (`self._discard_slug = True`) and `BadSlugQualityError` is re-raised; in the orchestrator it matches the first `isinstance` branch at `base_experiment.py:831` — the run fails but the loop *continues* (swallow-and-retry tier).

`NoSuitableVialError`: when `allow_user_requests` is enabled, the sampling code sends a `UserSetSamplesRequest` through the platform's `user_action_requester` and loops back to retry (`liquid_handler_sampling.py:899–919`). If the requester returns False (user aborted) or is absent, the error propagates. In `base_experiment.py:857` unrecognised exceptions hit the third tier: "The platform will shutdown." is logged and the exception is re-raised, terminating the `_run` thread after `_procedure_shutdown`.

`RecipeError`: raised purely from sampling logic (`liquid_handler_sampling.py:1412, 1521, 1568`) and handled generally as a halt-tier error (no explicit branch in `_run`).

## 7. Observability

The `Logger` (`Control Software/backend/Robochem_ML/robrains/base_classes/logger.py`) is a class-level singleton. On first `log_message` call it lazily spawns a uvicorn subprocess hosting a FastAPI WebSocket server (`:42–75`) and opens a browser window pointing at `http://localhost:6999`. Messages are POSTed to `/log` with a 50 ms timeout (`:264`) — if the server is slow, the post silently drops (`except Exception: pass`, `:267–268`). Messages are also appended to daily `logs/YYYY-MM-DD.txt` files and per-origin subfolders (`:235–272`).

The server (`websocket_logger.py:175–256`) holds a 1000-line ring buffer (`MAX_HISTORY`), an asyncio `LOG_QUEUE`, and a set of connected `CLIENTS`. The `_broadcaster` task fans each queued line out to all websocket clients (`:181–196`). New clients get the full history replayed on connect (`:226–227`). Log levels are tagged `error`, `warning`, `ok` (`:117–121`) and colorized via Colorama. `atexit.register(Logger.shutdown_log_server)` (`:281`) cleans up the subprocess.

## 8. Known gaps / risks

- **No wired emergency-stop button.** `07_Run_Platform.py:116` reserves a column for it but only Shutdown is implemented, which still lets the current run finish — there is no software interrupt that immediately halts motion. Physical cutoff is the only fast abort.
- **Best-effort log transport.** The WebSocket path uses a 50 ms POST timeout and silently swallows failures (`logger.py:264–268`); under load, errors can be dropped from the live stream even though the files still get them. ML-side divergence has no dedicated exception type and relies on generic `ValueError` handling in `base_experiment.py:833`, which silently retries.
- **Restart-loop can mask systemic failure.** The middle tier (`base_experiment.py:835–856`) catches `DeviceCommunicationError`, `HardLimitError`, `AlarmLockError` and unconditionally restarts the platform. There is no retry counter — a repeatedly-failing endstop will loop `build → fail → build` indefinitely, burning reagents and log volume.
- **`ContinuousMonitoring` swallows exceptions.** Errors in `monitored.update()` are logged as warnings only (`monitoring.py:233–234`), so a silently dead sensor cannot itself abort the run; only downstream tasks that depend on the reading will surface the problem.

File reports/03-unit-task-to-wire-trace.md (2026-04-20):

# 03 — Unit Task → Wire Trace

This report follows two unit-task objects from the orchestration layer down to the ASCII bytes on the serial wire and the matching firmware handler. The protocol is a line-oriented ASCII dialogue at 9600 baud, defined by `ArduinoDevice` in `device_arduino.py`: writes take the form `Sx=y\n`, reads take the form `Rx\n`, where `x` is a per-parameter integer id.

## Example 1 — `PumpVolume` → syringe-pump `pump` (variable 9)

### a. Unit task

`PumpVolume._execute_pump` (the template method invoked by `run`) computes what to pump and writes it to the device using `dict`-style assignment. The interesting write is `pump["pump"] = volume` (uL).

`Control Software/OmniPlatypus/OmniPlatypus/omniplatypus/procedures/unit_tasks/driving/driving_pumps.py:609-718`:

```python
pump["flowrate"] = flowrate
if pump.has_valve():
    pump["valve_setpoint"] = valve_position
pumping_event.set()
pump["pump"] = volume            # <-- the pump command
pumping_event.clear()
actual_volume_pumped = available_volume - pump["volume"]
```

### b. Device method

There is no specialized "pump()" method on `SyringePump`; the `__setitem__` dispatch lands in the subclass `_write`, which applies pre-write safety checks (available volume, syringe capacity), adjusts the acknowledge timeout to the expected pumping duration, then delegates to `ArduinoDevice._write`.

`Control Software/OmniPlatypus/OmniPlatypus/omniplatypus/devices/nrg/syringe_pump.py:855-896`:

```python
def _write(self, parameter, value):
    if parameter is self._parameter_pump:
        current_volume = self.__getitem__("volume")
        if current_volume - value < 0.0: ...   # raise ParameterError
    if parameter.write_acknowledge:
        if parameter is self._parameter_pump:
            parameter.acknowledge_timeout = (
                self.pumping_time(value) * self._timeout_multiplier)
    ArduinoDevice._write(self, parameter, value)
```

### c. `BaseDevice.__setitem__`

`BaseDevice.__setitem__` performs access/enabled/type checks, calls `parameter.validate(value)`, then `self._write(parameter, value)` (device-specific).

- `Control Software/OmniPlatypus/OmniPlatypus/omniplatypus/devices/base/device.py:897-936` — `__setitem__` implementation (checks + `_write` call at line 934).
- `Control Software/OmniPlatypus/OmniPlatypus/omniplatypus/devices/base/device.py:790-850` — `_check_device_parameter` that gates the call.

The `pump` parameter is `ArduinoParameter(name="pump", internal_id=9, write_acknowledge=True, acknowledge_value="k", stop_command="S21=RUN\n")` — registered in `syringe_pump.py:359-372`.

### d. Serial write

`ArduinoDevice._write` takes the lock, formats the command, and writes ASCII bytes. The command string is built by `_command_write`:

`Control Software/OmniPlatypus/OmniPlatypus/omniplatypus/devices/base/device_arduino.py:549-566`:

```python
def _command_write(self, parameter, value):
    if parameter.to_serial_string is not None:
        value_string = parameter.to_serial_string(value)    # float -> "250.0"
    elif isinstance(value, ArduinoValue):
        value_string = value.to_serial_string()
    else:
        value_string = str(value)
    return f"S{parameter.internal_id}=" + value_string + "\n"
```

The actual `write` call is at `device_arduino.py:768-771`:

```python
command = self._command_write(parameter, value)
self._serial_iface.write(command.encode("ascii"))
if parameter.write_acknowledge:
    self._receive_acknowledge(parameter)
```

For `PumpVolume.run(pump, volume=250.0)` the 7 bytes pushed onto the wire are: `S9=250.0\n` (that is `0x53 0x39 0x3D 0x32 0x35 0x30 0x2E 0x30 0x0A`). `pyserial` is configured at 9600 baud, 1 s write/read timeout in `ArduinoDevice.__init__` (`device_arduino.py:418-421`).

### e. Firmware handler

The Arduino UNO parses `S9=...` in the write switch statement. Variable 9 is documented at the top of the file (`syringe_pump_nrg.ino:23`) and handled at:

`Devices/Syringe Pump/Firmware/syringe_pump_nrg/syringe_pump_nrg.ino:424-436`:

```c
case 9:
    // Pump this much [uL]
    if (!motor.enable()) { error_type = ERROR_PUMP_MOTOR; ... break; }
    variable_value_float = Serial.parseFloat();
    motor.move(long(variable_value_float * steps_per_ml / 1000));
    moving_motor = true;
    break;
```

### f. Ack / response format

Because `write_acknowledge=True`, the host blocks in `_receive_acknowledge` (`device_arduino.py:632-696`) until a single ASCII line arrives. When the stepper finishes, the firmware emits `ACK_PUMPING 'k'` followed by `\n` (macro at `syringe_pump_nrg.ino:112`; `Serial.println('k')` paths at lines 430, 450, 468). A bad ack is `'n'` (`BAD_ACK_PUMPING`, line 113). The timeout is dynamically sized from `pumping_time(value) * 1.2` in `_write` above; an early stop sends the parameter's `stop_command` (`S21=RUN\n`), after which the device still emits the original `k`.

## Example 2 — `SetLightSourceIntensity` → lights-array proxy `intensity`

### a. Unit task

`SetLightSourceIntensity._execute` enables the array if needed, then writes the per-source intensity through the proxy's `__setitem__`.

`Control Software/OmniPlatypus/OmniPlatypus/omniplatypus/procedures/unit_tasks/reactor/light.py:41-60`:

```python
def _execute(cls, source, intensity):
    intensity = round(intensity)
    source_parent: LightArray = source.parent
    if intensity == 0:
        source["intensity"] = intensity       # <-- proxy write
        ...
    else:
        if source_parent["enable"] == "OFF":
            source_parent["enable"] = "ON"
        source["intensity"] = intensity       # <-- proxy write
```

### b. Device method

`LightSource` is a `ProxyArduinoDevice` attached to a `LightArray`. The proxy registers an `intensity` parameter whose `internal_id` is computed from the array slot:

`Control Software/OmniPlatypus/OmniPlatypus/omniplatypus/devices/nrg/light.py:75-88`:

```python
parameter = ArduinoParameter(
    name="intensity",
    access_level=ParameterAccess.RW,
    value_type=int,
    internal_id=base_variable_number,   # 20 + 10*array_index  (light.py:69-70)
)
parameter.min_value = 0
parameter.max_value = 100
self.add_parameter(parameter)
```

`base_variable_number` is computed in `array_arduino.py:43-55` as `_array_parameter_begin + _array_parameter_period * _array_index` — i.e. source 0 → id 20, source 1 → id 30, source 2 → id 40, source 3 → id 50.

### c. `BaseDevice.__setitem__`

Same generic path as Example 1 — `device.py:897-936`. The proxy does not override `_write`; it inherits `ArduinoDevice._write` via `ProxyArduinoDevice` (which forwards to the shared `_serial_iface` / `_serial_thread_lock` of its parent array), so the write reaches `ArduinoDevice._write` unchanged.

### d. Serial write

The same path as in Example 1 (`device_arduino.py:549-566` then `:768-771`). For `SetLightSourceIntensity.run(source_0, intensity=75)` the bytes on the wire are:

```
S20=75\n       -> 0x53 0x32 0x30 0x3D 0x37 0x35 0x0A
```

For source index 2 it would be `S40=75\n`. Intensity is declared `value_type=int`, so no `to_serial_string` override applies and plain `str(value)` is used (`_command_write` fallback branch).

### e. Firmware handler

The lights-array firmware splits variable ids: device-wide variables use the low ids, while ids `>= SERIAL_ARRAY_BEGIN` (20) are decoded to `(sub_id, local_var)` by `parse_array_command`. Local var 0 is the intensity setpoint.

`Devices/Photochemical Reactor Controller/Firmware/Lights_Array/Lights_Array.ino:374-403`:

```c
else if (command == 'S') {
    variable_number = Serial.parseInt();   // e.g. 20
    ...
    if (variable_number >= SERIAL_ARRAY_BEGIN) {
        parse_array_command(variable_number, sub_id);
        switch (variable_number) {                    // now local 0..4
            case 0:
                variable_value_int = Serial.parseInt();
                if (variable_value_int <= 100 && variable_value_int >= 0)
                    subdevices[sub_id].set_setpoint(variable_value_int);
                else { error_type = ERROR_SERIAL; ... }
                break;
```

### f. Ack / response format

The `intensity` parameter does not set `write_acknowledge`, so the host does not block for an ack. After the write, `ArduinoDevice._write` runs `_verify_error_register` in its `finally` clause (`device_arduino.py:778-779` and `:731-749`), which issues `R9\n` and parses the error-register reply in the `"type-value"` format (`ArduinoError.from_serial_string`, `device_arduino.py:184-197`). If `type != 0`, a matching `DeviceError` subclass is raised. A companion `enable` write on the parent array (also `Sx=y` with int 0/1 on id 3) uses the same silent pattern.

## General pattern (summary)

Every unit task is a thin classmethod-only orchestration layer over `device[name] = value` / `value = device[name]`. The reusable pipeline for a write is: unit task computes domain values → `BaseDevice.__setitem__` (`device.py:897`) validates and logs → concrete device `_write` injects policy (pre-checks, dynamic ack timeouts, cache invalidation) → `ArduinoDevice._write` (`device_arduino.py:751`) acquires the per-port `Lock`, flushes stray input, formats `Sx=y\n` with `_command_write` (`:549`), and writes ASCII at 9600 baud. If the parameter has `write_acknowledge`, `_receive_acknowledge` blocks for a single-line response matching `parameter.acknowledge_value` (e.g. `'k'`), otherwise `_verify_error_register` polls `Rerror\n` and raises typed exceptions on non-zero codes. Array devices reuse the same frame by encoding proxy index as `begin + period*index + local_id`, so the firmware switch-on-id in `Lights_Array.ino` decodes both device-wide and per-source variables with the same `Sx=y` grammar.

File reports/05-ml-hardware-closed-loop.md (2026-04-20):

# 05 — ML ↔ Hardware Closed Loop

This report traces the data path that lets RoboChem's Bayesian optimizer steer a physical reactor. It covers how a proposed experimental point is conjured from a Gaussian‑Process posterior, how it gets serialized into a concrete hardware recipe (vials, concentrations, volumes, temperatures), how the hardware hands back a `RunResult`, and how that result is folded back into the training set for the next iteration. All citations are to files in `Control Software/`.

## 1. Architecture: Producer/Consumer Queues

The ML side and the experiment side run in **separate threads** and communicate only through `queue.Queue` objects. On the experiment side (`OmniPlatypus/omniplatypus/procedures/experiments/base_experiment.py:199-204`) the `BaseExperiment` owns four thread‑safe queues:

```python
self._run_requests_queue = Queue()   # ML → hardware (recipes)
self._run_results_queue  = Queue()   # hardware → ML (RunResult)
self._user_action_queue  = Queue()
self._samples_queue      = Queue()
```

The experiment thread pulls from `_run_requests_queue` via `submit_run()` (line 442) and pushes `RunResult` objects to `_run_results_queue`, consumed by the ML side through `get_result()` (line 467).

On the ML side, `ML_Platform.com_prime()` (`ml_platform.py:211-228`) creates the **control-plane queues**:

```python
self.visual_queue = Queue()     # results_df snapshots for the frontend
self.HITL_queue   = Queue()     # frontend → ML (human-in-the-loop)
self._stop_event  = Event()
self.experiment   = kwargs.get("experiment", None)
```

The handshake is intentionally narrow: the ML side never touches hardware objects and the experiment never touches `torch` tensors. Everything crossing the boundary is a typed Python object (`list[ExperimentalParameter]` going out, `RunResult` coming in).

```mermaid
flowchart LR
    subgraph ML["ML Platform thread (_run)"]
      P[first_run: initial points]
      U[update → _BO_step]
      FM[_from_machine]
      TM[_to_machine]
      DF[(results_df)]
    end
    subgraph HW["Experiment thread"]
      Q1[[_run_requests_queue]]
      Q2[[_run_results_queue]]
      EX[Hardware procedure]
    end
    P -->|torch.Tensor N×d| TM
    U -->|torch.Tensor N×d| TM
    TM -->|list ExperimentalParameter| Q1
    Q1 --> EX
    EX -->|RunResult| Q2
    Q2 --> FM
    FM --> DF
    DF --> U
    U --> V[[visual_queue → Frontend]]
```

## 2. `ML_Platform.run()` Step by Step

`run()` (`ml_platform.py:35-67`) bootstraps the loop. It first synchronously invokes `first_run()` (supplied by the specific optimizer backend) and then spawns a daemon `Thread` pointing at `_run`:

```python
self.first_run()
...
self._running_thread = Thread(target=self._run, name=thread_name)
self._running_thread.daemon = True
self._running_thread.start()
```

### 2.1 Priming (`first_run`)

For `SingleBayesianOptiBackend` (`singlebayesianoptibackend.py:469-549`), `first_run()` samples an initial design:

1. If a `results_df` already exists from a prior session, it subtracts already‑finished runs from `"Number of initial points"` and resumes (lines 508-536).
2. Otherwise, `initialise_parameter(...)` draws `extra_points` samples, honoring `"Initialisation Method"` (LHS or Random) and `"force_categorical"`.
3. The resulting tensor `self.initial_x` is passed to `self.out_data(self.initial_x)` which calls `_to_machine` per row and submits each to the hardware queue.

### 2.2 Main Loop (`_run`)

`_run` (`ml_platform.py:119-182`) polls the experiment queue and reacts as results arrive:

```python
while not self._stop_event.is_set():
    data = self.experiment.get_result(block=False)
    if data is None:
        self._stop_event.wait(1)
        continue
    run_index, x, y, y_var, vial_idx, save_file_name = self._from_machine(data)
    self.in_data(run_index, x, y, y_var, vial_idx)
    self.visual_queue.put(self.results_df.copy())
    if self.check_batch(run_index, x, y, vial_idx):
        self.update()
```

`check_batch` (`ml_platform.py:196-209`) returns `True` only when no row in `results_df` still has `status == "submitted"` — i.e. the batch is drained. Only then is `update()` invoked and a new batch proposed.

### 2.3 Refitting (`update` → `_BO_step`)

`update()` (`singlebayesianoptibackend.py:671-734`) orchestrates one full BO iteration:

1. `_process_data()` re‑materialises `train_x`, `train_y`, `train_y_var` from the DataFrame via `_from_df`.
2. If retries are pending it short‑circuits: `self.out_data("failures")`.
3. `_check_adaptive()` optionally tunes exploration factors based on the last 3 targets.
4. `train_y` is normalized with `ColumnNormalizer` (mins/ranges, `utils.py:663-688`).
5. The termination criterion (`max_iter`) can emit `self.out_data("stop")`.
6. `_BO_step()` fits the surrogate, optimizes the acquisition, and emits next points via `out_data(next_point, predicted_y=...)`.

## 3. `ToandFromMachine`: Tensor ↔ Recipe

`ToandFromMachine` (`Control Software/backend/ml_backends.py`) is mixed in with the platform backends (line 838 onward) because this translation is OmniPlatypus‑specific. It owns two key methods.

### 3.1 `_to_machine(tensor)` — Tensor → Recipe

For each `MLParameter` in `self.ML_parameters`, it looks up the parameter's slot in `self.check_dict` (populated by `_generate_check_dict`, `communication_module.py:995-1155`) and back‑translates:

```python
if f"{param_name}_continuous" in self.check_dict:
    tensor_continuous_value = tensor[self.check_dict[f"{param_name}_continuous"]]
    value_continuous = parameter.back_translation_continuous(
        tensor_continuous_value.item()
    )
```

`back_translation_continuous` maps `[0,1] → [min,max]` in natural units (e.g. mM, °C). Discrete slots are decoded via `back_translation_discrete`, task slots via `back_translation_task`, and multi‑fidelity slots via `back_translation_fidelity` (`ml_backends.py:110-143`; translators are generated in `mlparameter.py:544-681`).

Each parameter becomes either a `ChemicalParameter` (chemical identity + concentration, lines 148-157) or a `NumericalParameter`/`ExperimentalParameter` (lines 158-180) and is tagged with a `foreign_key` that remembers which ML parameter it came from — this is the label used to reverse the translation later.

Constants from `self.constants` (catalyst stock, solvent, analytical peaks, etc.) are appended unchanged (`ml_backends.py:186-257`), including special handling for `yield_calculation_chemical`, `target_peak` and `retention_time` which are looked up in a pandas DataFrame keyed by the chosen limiting reagent (lines 199-217).

The platform‑specific machinery (NMR pulse programs, HPLC tables, sample identifiers) is copied in from `self.parameter_machine`; the `sample_name` machine gets a run‑unique stamp:

```python
case "sample_name":
    to_append = copy.deepcopy(machine)
    name = f'run{self.run_index}_{time.strftime("%Y%m%d%H%M%S", time.localtime())}'
    to_append.value = to_append.value(name)
```

A sampling priority from `_sampling_priorities` (`ml_backends.py:53-73`) is attached to chemicals so the liquid‑handler dispatcher knows which reagent defines the slug.

### 3.2 `_from_machine(results)` — Recipe → Tensor

`_from_machine(results: RunResult)` (`ml_backends.py:276-391`) does the reverse:

1. Extracts `run_id`, `result`, `success`, `parameters`, `collection_vial_id` from the `RunResult` (schema in `experiment_parameters.py:222-240`).
2. If `success=False` it returns `(run_id, None, None, None, vial_idx, None)` so the platform can mark the run failed.
3. `calculate_metrics(targets, recipe)` (lines 441-533) turns the raw target dict (yield, conversion, integrals, etc.) into whatever `self.targets` asks for — including derived metrics like `throughput`, `selectivity`, `cost_per_unit_product`, `enantiomeric excess`, `diastereomeric ratio`. `y` and `y_var` are packed as `torch.float64` tensors of length `len(self.targets)`.
4. The x‑tensor is rebuilt by walking `recipe`, matching each `foreign_key` back to an `MLParameter`, calling the forward translators, and writing the value into `tensor_x[check_dict[...]]`.

## 4. `SingleBayesianOptiBackend`: The Optimizer Math

### 4.1 Model Construction

`_init_model` picks a constructor from `self.constructors` (`singlebayesianoptibackend.py:143-151`). The default `SingleTaskGP` uses `Standardize(m=1)` for y‑normalization; `MixedSingleTaskGP` adds `cat_dims=self.categoricals_indexes` and a custom kernel; `NoisySingleTaskGP` plumbs variance via `train_Yvar`. Multi‑output problems assemble a `ModelListGP(*per_target_gps)` (`singlebayesianoptibackend.py:938-955`):

```python
for i in range(y.shape[1]):
    gp = model_constructor(train_X=x, train_Y=y[:, i:i+1], **kwargs_copy)
    mll = ExactMarginalLogLikelihood(gp.likelihood, gp)
    fit_gpytorch_mll(mll)
    models.append(gp)
self.model = ModelListGP(*models).to(device)
```

The inputs to the GP live in a normalized tensor space whose bounds come from `_generate_check_dict` (`communication_module.py:995-1155`): continuous slots bound to `[0,1]`, one‑hot categoricals to `[0,1]` per dim, high‑cardinality categoricals to `[0, n-1]`. Target values are normalized with `ColumnNormalizer` before training and denormalized after prediction (`utils.py:696-717`).

### 4.2 Acquisition Choice

`_select_acq_constructor` (`singlebayesianoptibackend.py:799-856`) maps a user string to a BoTorch class:

- `"EI"` → `qLogExpectedImprovement` (qMC log‑EI — numerically stable for small EI).
- `"UCB"` → `UpperConfidenceBound` if q=1 else `qUpperConfidenceBound`, with `beta = parameters["Explorative Factor"]`.
- `"qEHVI"`/`"qLogNEHVI"` → hypervolume‑based multi‑objective acquisitions with a ref‑point 0.1 below the observed min (line 1139).
- `"qKG"` → `qKnowledgeGradient` for look‑ahead BO.
- `"qMVE"`, `"qNegIPV"`, `"MaxVariance"` → pure explorers, seeded with 1000/512 Sobol candidate sets (lines 1176, 1219).

`_optimize_acquisition_function` (`singlebayesianoptibackend.py:1272-1322`) runs the standard BoTorch multistart SLSQP/L‑BFGS pipeline:

```python
args = {
    "acq_function": acquisition_function,
    "bounds": bounds,
    "q": q,
    "num_restarts": 10,
    "raw_samples": 512,
    "options": {"with_grad": with_grad},
}
next_point, acq_value = optimize_acqf(**args)
```

`with_grad` is disabled for non‑differentiable surrogates (`RandomForest`, `SVR`). The returned `next_point` has shape `(q, d)`; `self.model.posterior(next_point)` is then denormalized to produce `predicted_y=(mean, std)` — stored as a `FloatWithError` in `results_df[f"{target}_predicted"]` (see `_to_df`, `communication_module.py:876-894`).

## 5. Human‑in‑the‑Loop Variants

`ML_Platform_HITL` (`ml_platform_hitl.py`) sets `_hitl_tag = True` and rewires `_run` so it **waits for the human** after a batch completes. Instead of directly calling `update()`, `_process_visual_queue()` (lines 79-96) polls `self.HITL_queue` in 10 s intervals; the frontend pushes a reviewed DataFrame via `put_HITL()` (line 146), which the loop passes to `in_data(df)`/`update()` to drive the next BO step. Because `_hitl_tag` is True, `_to_machine` skips the `yield_calculation_chemical` target lookup (`ml_backends.py:93-101`) since the human has already normalised the targets.

`ML_Platform_HITL_Development` (`ml_platform_hitl_development.py`) is the free‑form manual mode: the ML thread will not submit anything until the user seeds the loop via `put_HITL`, and `out_data(tensor_from_machine)` simply ticks `check_batch` — the user is expected to hand‑assemble recipes with `send_to_platform`.

## 6. Multi‑Task, Multi‑Fidelity, Multi‑Objective

- **Multi‑task** (`allscopetaskbackend.py`): `AllScopeTaskBackend` wraps `MultiTaskGP` so a single surrogate sees data from multiple substrates with a task index (generated by `_translation_task`, `mlparameter.py:630-643`). At acquisition time a `FixedFeatureAcquisitionFunction` pins the task feature to the currently active substrate while still leveraging correlated data from siblings. `ScopeAcceleratorTaskBackend` is the 2‑task transfer variant.
- **Multi‑fidelity** (`scopeacceleratorfidelitybackend.py`): uses `SingleTaskMultiFidelityGP`; the fidelity slot (`[0,1]`) is wired through `translation_fidelity` and ejected from `bounds` by `_adjust_bounds` when the acquisition should only see the target fidelity.
- **Multi‑objective** (`enantioextravaganza.py`): `EnantioExtravaganzaBackend._BO_step` proposes **one highly‑exploitative candidate per target** (one‑hot `ScalarizedPosteriorTransform`) and then adds Pareto‑front coverage candidates via `qLogNParEGO`/`qEHVI`/`qPPES`, using `set_X_pending` to make later candidates aware of earlier ones (lines 124-188). Near‑duplicates are filtered with `filter_close_points` (threshold 1e‑2 in normalized space).
- **Batched dual acquisition** (`efficientbatchedbobackend.py:162-228`): fits once then optimises an exploitative acquisition, marks its point as pending on an explorative one (`qKG`, `qMVE`, `MaxVariance`, or `qNegIPV`), and concatenates both for `out_data`.

## 7. Queue‑Boundary Data Contracts

| Direction | Object | Shape / Fields |
|---|---|---|
| ML → Hardware | `list[ExperimentalParameter]` | `ChemicalParameter(name, value, units, foreign_key, sampling_priority)`, `NumericalParameter`, `AnalyticalParameter`, plus `sample_name`, `collection_vial`, analytical pulse programs from `parameter_machine` |
| Hardware → ML | `RunResult` | `run_id: str`, `result: dict`, `success: bool`, `parameters: list[ExperimentalParameter]`, `collection_vial_id: str|None`, `exception: Exception|None` (`experiment_parameters.py:222-240`) |
| ML internal x | `torch.Tensor` | `(q, d)` `float64` in normalized `[0,1]^d` (with one‑hot / task / fidelity slots) |
| ML internal y | `torch.Tensor` | `(n_finished, len(targets))` `float64`, normalized by `ColumnNormalizer` for training, denormalized for reporting |
| ML → Frontend | `pd.DataFrame` | `results_df` snapshot pushed to `visual_queue` after every ingest |
| Frontend → ML | `pd.DataFrame` (HITL) | Reviewed copy of `results_df` with targets filled in, pushed to `HITL_queue` |

The `foreign_key` attribute stapled onto each `ExperimentalParameter` in `_to_machine` is the crucial load‑bearing identifier: it is what lets `_from_machine` rebuild `tensor_x` without having to know the hardware ordering. When a `RunResult` comes back, every parameter whose `foreign_key` matches an `MLParameter.name` is translated through the forward translator and written into the correct `check_dict` slot of a fresh `tensor_x`. Constants and machine‑only parameters have no `foreign_key` match and are silently skipped (`ml_backends.py:325-330`).

That single convention — "hardware recipes carry their ML provenance as a foreign key, the ML side keeps no state about hardware layout" — is what lets a BoTorch optimizer talk to an autonomous flow reactor with only two thread‑safe queues between them.

## Key File References

- `/home/user/robochem_flex/Control Software/backend/ml_backends.py` — `ToandFromMachine` (75-391), metric calculators (441-533), omni‑platform composition classes (838-914).
- `/home/user/robochem_flex/Control Software/backend/Robochem_ML/robrains/communication_module/ml_platform.py` — `run`, `_run`, `check_batch`, `in_data`, `out_data`, `com_prime` (35-336).
- `/home/user/robochem_flex/Control Software/backend/Robochem_ML/robrains/communication_module/communication_module.py` — `baseMLBackend`, `ML_prime`, `_generate_check_dict`, `_to_df`, `_from_df` (24-1198).
- `/home/user/robochem_flex/Control Software/backend/Robochem_ML/robrains/ml_modules/singlebayesianoptibackend.py` — `first_run`, `update`, `_BO_step`, `_init_model`, `_select_acq_constructor`, `_optimize_acquisition_function`.
- `/home/user/robochem_flex/Control Software/backend/Robochem_ML/robrains/ml_modules/efficientbatchedbobackend.py` — dual‑acquisition variant.
- `/home/user/robochem_flex/Control Software/backend/Robochem_ML/robrains/ml_modules/allscopetaskbackend.py`, `scopeacceleratortaskbackend.py`, `scopeacceleratorfidelitybackend.py`, `enantioextravaganza.py` — task / fidelity / multi‑objective backends.
- `/home/user/robochem_flex/Control Software/backend/Robochem_ML/robrains/parameter_backends/mlparameter.py` — `generate_translators` (544-681).
- `/home/user/robochem_flex/Control Software/OmniPlatypus/OmniPlatypus/omniplatypus/procedures/experiments/base_experiment.py` — `submit_run` (442), `get_result` (467), queue wiring (199-204).
- `/home/user/robochem_flex/Control Software/OmniPlatypus/OmniPlatypus/omniplatypus/procedures/experiments/experiment_parameters.py` — `RunResult` (222-240).

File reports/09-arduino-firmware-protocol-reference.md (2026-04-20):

# 09 — Arduino Firmware Protocol Reference

This report documents the low-level serial protocol exposed by every Arduino-based controller in `robochem_flex`. The host side (`device_arduino.py`) is covered elsewhere; the focus here is the firmware side.

## 1. Canonical Protocol

Every controller (except the Cartesian Sampler auxiliary axis) implements an identical ASCII, line-oriented protocol over USB-Serial at **9600 baud, 8N1**.

| Element | Specification |
|---|---|
| Baud rate | 9600 (`Serial.begin(9600)`) |
| Framing | ASCII; `\n` (LF) terminates responses. Commands are parsed char-by-char via `Serial.parseInt()`/`parseFloat()` and do not strictly require a terminator, but the host sends `\n`. |
| Write command | `Sx=y` — set variable `x` (int) to value `y` (int/float/string). The `=` is consumed by a bare `Serial.read()` between the index and value. |
| Read command | `Rx` — read variable `x`; firmware replies with a single `\n`-terminated value. |
| Error register format | `<type>-<value>\n` (see per-device error tables). Reading it resets the register. |
| Unknown variable | Silently sets the error register to `type=1, value=<variable>`; no line is emitted. |
| Asynchronous events | Controllers may emit unsolicited lines (valve/pump ACKs, phase-sensor state-change messages). The host must tolerate this. |
| Reserved index | `0` is never valid — `Serial.parseInt()` returns `0` on parse failure. |

Representative command parser (Syringe Pump, `syringe_pump_nrg.ino:225-235`):

```cpp
while (Serial.available() > 0) {
    char command = Serial.read();
    int variable_number = 0;
    if (command == 'R') {
        variable_number = Serial.parseInt();
        switch (variable_number) { /* ... per-variable readers ... */ }
    } else if (command == 'S') {
        variable_number = Serial.parseInt();
        Serial.read();              // discards '='
        /* Serial.parseInt/parseFloat reads the value */
    }
}
```

All five main-loop controllers follow this pattern. Array-style variables (indices ≥ `SERIAL_ARRAY_BEGIN`) are decoded with `parse_array_command()`: `sub_id = (idx - BASE) / PERIOD`, `sub_idx = (idx - BASE) % PERIOD`.

## 2. Per-Controller Reference

### 2.1 Syringe Pump (`syringe_pump_nrg.ino`)

Source: `/home/user/robochem_flex/Devices/Syringe Pump/Firmware/syringe_pump_nrg/syringe_pump_nrg.ino`.

| # | RW | Type | Meaning |
|---|---|---|---|
| 1 | RW | str[20] | Device identifier |
| 2 | RW | int[0-1] | Pump ACK enable (default 1) |
| 3 | RW | int[0-1] | Main valve setpoint (Runze 2-way) |
| 4 | RO | int[0-2] | Main valve position (2 = error) |
| 5 | RW | float | Syringe diameter [mm] |
| 6 | RW | float | Steps per mL [1/mL] (overridden by writing 5) |
| 7 | RW | float | Flow rate [mL/min] |
| 8 | RW | int[0-1] | Stepper driver enable |
| 9 | W  | float | Pump this volume now [µL] (signed) |
| 10 | RO | float | Volume remaining on current pump [µL] |
| 11 | RW | float | Volume currently in syringe [µL] |
| 12 | W  | int[0-2] | Zero syringe (0 empty / 1 full / 2 software-only) |
| 13 | RO | `t-v` | Error register (resets on read) |
| 14 | W  | — | Save defaults to EEPROM |
| 15 | W  | — | Factory reset |
| 16 | RW | int[0-1] | Auxiliary valve setpoint |
| 17 | RO | int[0-2] | Auxiliary valve position |
| 18 | RW | int[0-1] | Encoder wheel enable (line 294, gated on `WITH_ENCODER`) |
| 19 | RW | int[0-1] | Main-valve ACK enable |
| 20 | RW | int[0-1] | Aux-valve ACK enable |
| 21 | W  | — | Stop current movement |
| 22 | RO | float | Max no-accel flow [mL/min] |
| 23 | RO | float | Acceleration [mL/min²] |
| 24 | RW | int | Steps since last encoder interrupt (diagnostic) |

Async ACK characters (line 112-115): `'k'` = pump done, `'n'` = pump failed, `'v'` = main valve done, `'a'` = aux valve done.

Error codes (line 117-121): `0` none; `1` serial (value = bad var #); `2` valve; `3` motor (value is `MOTOR_ERROR_*` from `AsyncStepper.h:40-45`: `1` endstop+, `2` endstop–, `3` delay range, `4` disabled, `5` blocked/stalled).

**`loop()`** (line 569-610): Calls `parse_serial()` continuously and polls `valve.ready()`, `valve_aux.ready()`, and `motor.ready()` — emitting the corresponding ACK character when each completes. Motor errors raised during the move are folded into the error register and trigger `'n'` instead of `'k'`.

### 2.2 Photochemical Reactor Controller (`Lights_Array.ino`)

Source: `/home/user/robochem_flex/Devices/Photochemical Reactor Controller/Firmware/Lights_Array/Lights_Array.ino`.

Device-wide variables (`SERIAL_ARRAY_BEGIN = 20`):

| # | RW | Type | Meaning |
|---|---|---|---|
| 1 | RW | str[20] | Device identifier |
| 2 | RO | int | Number of subdevices (= 4) |
| 3 | RW | int[0-1] | SSR power-enable for all lights |
| 4 | RO | int | Measured supply current [mA] |
| 5 | RW | int[0-1024] | Current-sense offset |
| 6 | RW | int | Current-sense proportional factor |
| 7 | RO | float | Measured supply voltage [V] |
| 8 | RW | float | Voltage-sense proportional factor |
| 9 | RO | `t-v` | Error register (resets on read) |
| 10 | W | — | Save defaults |
| 11 | W | — | Factory reset |

Array variables, one set per light (`idx = 20 + 10·sub_id + i`, `sub_id ∈ 0..3`):

| i | RW | Type | Meaning |
|---|---|---|---|
| 0 | RW | int[0-100] | Intensity setpoint [%] |
| 1 | RW | float | Calibration (% → PWM raw) |
| 2 | RW | float | PID P constant |
| 3 | RW | float | PID I constant |
| 4 | RW | float | PID D constant |

Error codes (line 65-67): `0` none; `1` serial; `2` analog-out subsystem (see `Analog_out.h`, constant `ANALOGOUT_ERROR_OK = 0`).

**`loop()`** (line 521-527): tight `parse_serial()` loop. Closed-loop control is done in the `TIMER1_COMPA` ISR (line 533-540) every 100 ms, which calls `subdevices[i].update()` to drive each PID.

### 2.3 Phase Sensor Controller (`Phase_Sensor_Array.ino`)

Source: `/home/user/robochem_flex/Devices/Phase Sensor Controller/Firmware/Phase_Sensor_Array/Phase_Sensor_Array.ino`.

Device-wide variables (`SERIAL_ARRAY_BEGIN = 10`):

| # | RW | Type | Meaning |
|---|---|---|---|
| 1 | RW | str[20] | Device identifier |
| 2 | RO | int | Number of sensors (= 4) |
| 3 | RO | digits+`;` | Read all sensors (e.g. `1123;`) |
| 4 | RO | `t-v` | Error register (resets on read) |
| 5 | W | — | Save defaults |
| 6 | W | — | Factory reset |

Array variables per sensor (`idx = 10 + 10·sensor_id + i`):

| i | RW | Type | Meaning |
|---|---|---|---|
| 0 | RO | int[0-3] | Phase (0 err / 1 clear / 2 opaque / 3 gas — `OCB350.h:17-23`) |
| 1 | RO | int[0-1023] | Raw analog value |
| 2 | RW | int[0-2] | Monitor mode: `NO`/`ONCE`/`ALWAYS` |
| 3 | W | — | Run hardware calibration (tube must be dry) |

Error codes: `0` none; `1` serial.

Async message format: `<sensor_id>=<phase>\n` emitted from `loop()` when `sensors[i].has_changed()` returns true.

**`loop()`** (line 324-338): `parse_serial()` plus a per-sensor change-detection poll that calls `has_changed()` (which respects the `OCB_MIN_TIME` debounce from `OCB350.h:12`) and publishes state-change events.

### 2.4 General Purpose Controller (`GPIO_Array.ino`)

Source: `/home/user/robochem_flex/Devices/General Purpose Controller/Firmware/GPIO_Array/GPIO_Array.ino`.

Device-wide variables (`SERIAL_ARRAY_BEGIN = 10`):

| # | RW | Type | Meaning |
|---|---|---|---|
| 1 | RW | str[20] | Device identifier |
| 2 | RO | int | Number of GPIOs (= 10, pins D2–D12, skipping D13 LED) |
| 3 | RO | int | Number of analog inputs (= 6, A0–A5) |
| 4 | RO | `t-v` | Error register (resets on read) |
| 5 | W | — | Save defaults |
| 6 | W | — | Factory reset |

Array — digital pins (`gpio_id = pin − 2`, indices `10..109`):

| i | RW | Type | Meaning |
|---|---|---|---|
| 0 | RW | int[0-2] | Pin mode: output (0) / input (1) / PWM (2) |
| 1 | RO | int[0-1] | Digital read |
| 2 | RW | int[0-1] | Digital write (read returns last setvalue) |
| 3 | RW | int[0-255] | PWM duty (PWM-capable pins only) |

Array — analog inputs (`gpio_id = analog_pin + 11`, indices `120..170`):

| i | RW | Type | Meaning |
|---|---|---|---|
| 0 | RO | int[0-1023] | `analogRead()` |

Error codes (line 63-65, plus `GPIO.h:12-19`): `0` none; `1` serial; `2` pin error where value ∈ {`1` no PWM, `2` bad digital value, `3` bad PWM value, `4` write-to-input, `5` read-from-output, `6` invalid mode, `7` wrong-mode-for-op}.

**`loop()`** (line 352-358): a pure `parse_serial()` loop — the controller is completely reactive.

### 2.5 Cartesian Sampler — Auxiliary Axis (`auxiliary_axis.ino`)

Source: `/home/user/robochem_flex/Devices/Cartesian Sampler/Firmware/auxiliary_axis/auxiliary_axis.ino`.

This controller does **not** use the `Sx=y`/`Rx` protocol. It has no Serial interface. It drives a servo on `D9` between `POSITION_UP = 150` and `POSITION_DOWN = 75` (lines 3-5) based on a single digital input pin (`D2`). The LED on `D13` mirrors the state. Motion is rate-limited by a `DELAY = 5` ms per-degree step (lines 36-45).

Interface: `D2 HIGH` → axis drops; `D2 LOW` → axis rises. This is typically driven by a GPIO pin on the main Cartesian-sampler controller.

## 3. Device Identity (`Device_id.h`/`.cpp`)

Every controller ships an identical `Device_id` module (e.g. `/home/user/robochem_flex/Devices/Syringe Pump/Firmware/syringe_pump_nrg/Device_id.h:10-15`):

| Symbol | Definition |
|---|---|
| `DEVICE_ID_SIZE` | 20 (bytes) |
| `DEVICE_ID_CHAR_TIMEOUT` | 20 ms per char |
| `char device_id[20]` | Global buffer (`Device_id.cpp:11`) |

**Startup:** `setup()` calls `load_defaults()`, which reads an EEPROM check byte (`DEFAULT_CHECK = 42`). If present, `eeprom_get_id()` (`Device_id.cpp:37-47`) loads the stored name; otherwise `factory_reset()` writes a hard-coded default:

| Controller | Default ID |
|---|---|
| Syringe Pump | `SYRINGE_PUMP_0` |
| Photochemical Reactor | `LIGHTS_0` |
| Phase Sensor | `PHASE_ARRAY_0` |
| General Purpose | `GPIO_0` |

**Read:** `R1` prints `device_id\n`. **Write:** `S1=` followed by up to 20 chars terminated by `\n`, consumed by `serial_read_id()` (`Device_id.cpp:49-70`). The host uses this string for device discovery/matching.

## 4. Safety Interlocks in Firmware

The main safety-critical device is the syringe pump. Its interlocks live in `AsyncStepper.cpp`/`.h`:

| Mechanism | Defined in | Behaviour |
|---|---|---|
| Endstop pins | `AsyncStepper.h:41-42`, `syringe_pump_nrg.ino:108-109` | Two NO endstops (D8 neg, D9 pos). Active LOW. Unexpected activation → `MOTOR_ERROR_ENDSTOP_POS/NEG`. |
| Endstop debounce | `MAX_STEPS_SINCE_ENDSTOP = 6` (`AsyncStepper.h:24`) | A stop is only committed after 6 consecutive stepped reads show the endstop closed (`check_endstop()` at `AsyncStepper.cpp:336`). |
| Zero on hit | `endstop_stop()` (`AsyncStepper.cpp:321`) | Halts motion and zeros the absolute-position counter when an endstop closes during zeroing. |
| Stall detection (encoder) | `WITH_ENCODER`, `MAX_STEPS_SINCE_INT = 75` (`AsyncStepper.h:18,23`) | With the encoder wheel on D2 (INT0), every encoder pulse resets `steps_since_int`. If it exceeds ±75 the motor is considered blocked → `MOTOR_ERROR_BLOCKED`. Can be disabled at runtime via variable 18. |
| Step-delay clamp | `MIN_DELAY_US = 30`, `MAX_DELAY_US = 4_194_240` (`AsyncStepper.h:21-22`) | `set_step_delay()` returns `MOTOR_ERROR_DELAY_RANGE` outside this window, preventing ultra-fast commutation or stalls. |
| Disabled-driver guard | `MOTOR_ERROR_DISABLED` (lines 424-433, 443-453 of `.ino`) | `S9` (pump) and `S12` (zero, unless "software-only") reject the command and emit `'n'` if the driver is disabled. |
| Emergency stop | `S21` (line 519-530) | Host-driven hard-stop that aborts any pump/zero move in place and still returns the appropriate ACK. |
| EEPROM guard | `DEFAULT_CHECK = 42` byte | On boot, a corrupted/first-run EEPROM triggers `factory_reset()` instead of loading garbage calibration. Present in all four full controllers. |

Other controllers have lighter interlocks: the Lights controller tracks an `AnalogOut::error` static and returns it under variable 9, and the GPIO controller raises `GPIO_ERROR_WRITE_TO_INPUT`/`READ_FROM_OUTPUT`/`WRONG_MODE` on misuse (`GPIO.h:12-19`). None of them include a hardware watchdog — timing safety relies on the host refreshing setpoints and the blocking nature of the parser loops.

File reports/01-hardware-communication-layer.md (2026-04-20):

# 01 — Hardware Communication Layer

This report dissects the lowest layer of the `robochem_flex` self-driving lab stack: the code that sits between Python user procedures and the wires running to physical instruments. All code lives under `Control Software/OmniPlatypus/OmniPlatypus/omniplatypus/devices/`. The design is a single abstract parameter-oriented interface (`BaseDevice`) with three transport-specific subclasses (`ArduinoDevice`, `ModbusDevice`, `SocketDevice`) and a proxy/array pattern for sharing one transport among multiple logical sub-devices.

## 1. `BaseDevice`: the parameter abstraction

`BaseDevice` (`base/device.py:434`) is a pure abstract class. Every physical instrument (`nrg/syringe_pump.py`, `bronkhorst/mass_flow_controller.py`, `magritek/spinsolve.py`, etc.) inherits from one of its transport subclasses and exposes functionality as named parameters rather than method calls. Parameter metadata lives in `DeviceParameter` (`base/device.py:232`) and includes `name`, `access_level` (R/W/RW, `device.py:28`), `value_type`, `min_value`/`max_value`, `caching_policy` (`NEVER`/`TRY`/`ALWAYS`, `device.py:42`), a `stop: threading.Event` for asynchronous abort, and an `internal_id` that is the transport-specific address (an integer Arduino variable number, a Modbus register, a socket command code, etc.).

Parameters are registered by subclass constructors via `BaseDevice.add_parameter` (`device.py:549`), which warns on duplicate names or shared internal IDs. The life-cycle contract is documented at `device.py:482`: constructor → `open()` → `setup()` → `initialize()`. Access before the device is open raises `DeviceNotOpenError`; access before init raises `DeviceNotInitializedError` (`device.py:815–825`).

The pivot of the API is `__getitem__` / `__setitem__`, so user code always reads as `device["pressure"]` and writes as `device["setpoint"] = 3.0`. The read pipeline (`device.py:852`) is:

```python
def __getitem__(self, name: str) -> Any:
    parameter = self._check_device_parameter(name=name, write=False)
    if not parameter.caching_policy == ParameterCachingPolicy.NEVER:
        if parameter.last_known_value is not None:
            return parameter.last_known_value
        ...
    value = self._extract(parameter, self._read(parameter))
    parameter.last_known_value = value
    return value
```

Subclasses only override `_read`, `_write`, and optionally `_extract` (`device.py:749`–`788`). The default `_extract` just calls `parameter.value_type(response)`. Values can be rich objects: `ParameterValue`, `ParameterValueRun` (a guard type for commands that take no argument — you must construct it from the literal string `"RUN"`, `device.py:141`), and `ParameterEnumValue` backed by a `bidict` (`device.py:180`). `Snapshot` (`devices/snapshot.py:12`) captures parameter values and restores them verbatim using the same `[]` accessor; it is intended for settings, not live actuation state.

## 2. Serial transport: `ArduinoDevice`

`ArduinoDevice` (`base/device_arduino.py:361`) wraps `pyserial`. The protocol described in its docstring (`device_arduino.py:364–383`) is deliberately simple and **does not use CRC or checksums** — contrary to what one might assume, the only framing is ASCII with newline terminators:

- Write: `S<id>=<value>\n` (`device_arduino.py:566`, `_command_write`).
- Read: `R<id>\n` (`device_arduino.py:577`, `_command_read`). The response is a newline-terminated ASCII line.

Defaults: 9600 baud, 1 s read timeout, 1 s write timeout, set at `device_arduino.py:419–421`. `open()` writes the comport then sleeps 2 s via `pause.seconds(2.0)` (`device_arduino.py:466`) because opening the port strobes DTR and resets the Arduino. Reliability relies on three mechanisms instead of checksums:

1. **Per-device thread lock**. `_serial_thread_lock: Lock` is acquired around every transaction (`device_arduino.py:710`, `765`). An array of proxies shares the parent's lock so concurrent threads can address different sub-devices of the same Arduino without collisions.
2. **Optional acknowledge values**. A parameter may set `acknowledge_value: str | list[str]` and `read_acknowledge`/`write_acknowledge` flags. `_receive_acknowledge` (`device_arduino.py:632`) spins until one or more whole lines arrive, comparing them to `acknowledge_value`. Failure yields `ParameterTimeoutError` (`device_arduino.py:667`) or `ParameterAcknowledgeError` (`device_arduino.py:691`). Both can be downgraded to warnings via `<param>_ignore_timeout` and `<param>_ignore_badack` setup options auto-generated by `_generate_setup_options` (`device_arduino.py:811`). Example: `nrg/syringe_pump.py:213` sets `parameter.acknowledge_value = "v"` for the pump's volume command.
3. **Device-side error register**. Subclasses may assign `self._error_parameter` to an `ArduinoError` parameter (`device_arduino.py:143`). Every `_read` (except a read of the register itself) and every `_write` calls `_verify_error_register` in a `finally` block (`device_arduino.py:725–729`, `778`). The register encodes errors as `"<type>-<value>"`, parsed by the regex at `device_arduino.py:146`. The `exception()` method (`device_arduino.py:199`) looks up the failing parameter by internal id and raises a typed `DeviceError` subclass.

Additional reliability: `flush_buffer_in` (`device_arduino.py:521`) drains any stale bytes before each transaction; unsolicited bytes become a `ParameterCommError` unless `ignore_unexpected_data_warning` is set (`device_arduino.py:624`). If serial raises `SerialException` or `ValueError`, it is wrapped in `DeviceCommunicationError` (`device_arduino.py:719–723`). There are **no explicit retries** at this layer — a failure escapes to the caller. `reopen()` exists for higher-level recovery (`device_arduino.py:476`).

`ArduinoValue` (`device_arduino.py:37`) is a mixin that provides `to_serial_string`/`from_serial_string`. Parameters may also supply their own callable at `ArduinoParameter.to_serial_string` / `from_serial_string` (`device_arduino.py:286–311`); floats default to `round(value, float_rounding)` with `float_rounding=3` (`device_arduino.py:320`).

## 3. Modbus transport

`ModbusDevice` (`base/device_modbus.py:81`) uses `pymodbus.client.ModbusSerialClient` with `ModbusRtuFramer`. Connection defaults: 9200 baud, even parity, 1 stop bit, 8 data bits, 10 s timeout (`device_modbus.py:104–112`). A per-device `Lock` guards `open`/`close`. Note `is_open()` only returns the cached `self._connected` flag (`device_modbus.py:119`); there is no active liveness probe.

Parameters carry `register_type` — `HOLDING`, `COMMAND`, or `COMMAND_ACTION` (`device_modbus.py:40`) — plus an `internal_id` (address or command code), `internal_type` (`int`, `bin`, `Flag`) and `data_length` in registers. `_read` issues `read_holding_registers` (`device_modbus.py:150`) and, for multi-register values, runs the response through `_ntoh` (`device_modbus.py:143`) which uses `struct` to repack words into the final integer. `_write` distinguishes HOLDING (`write_registers` at the given address) from COMMAND/COMMAND_ACTION, which are always written to address `0x0000` as a pair `[command_code, value]` packed by `_hton` (`device_modbus.py:200–214`). Errors are signalled by pymodbus's `ModbusResponse.isError()`; on failure the response object itself is raised (`device_modbus.py:215`).

## 4. Socket transport

`SocketDevice` (`base/device_socket.py:14`) is a minimal base: it stores `(host, port)`, opens a blocking `AF_INET`/`SOCK_STREAM` socket, and exposes `reopen()`/`close()`. It defines no read/write protocol — each concrete device picks its own framing. Examples:

- `magritek/spinsolve.py:862` sends XML (`self._socket.sendall(request.encode())`) and reads with `recv(4096)` in a polling loop that assembles messages until a parameter-specific `end_of_response` tag is seen (`spinsolve.py:765–771`), with a timeout reset on every received chunk.
- `nrg/rama_berry.py:285` uses a length-prefixed binary frame: first reads 4 bytes of big-endian length, then drains 1024-byte chunks until satisfied.
- `nrg/chromtroller.py:155` wraps every transaction with `self._socket_lock` and uses `keep_open = False` (`chromtroller.py:152`) so it `reopen()`s per call and closes again in `finally` — effectively a lightweight "open → transact → close" RPC style.

There is no built-in automatic reconnection: reconnection is driven externally by whichever layer catches the `DeviceCommunicationError`. `is_open()` is just a null-check on `self._socket` (`device_socket.py:58`), so a half-closed peer will not be detected until the next I/O call fails.

## 5. `ArrayDevice` / `ProxyDevice`

`base/array.py` defines two thin interfaces: `ArrayDevice` holds a dict of sub-devices keyed by name (`array.py:61`, `proxy(name)`), and `ProxyDevice` is a sub-device that stores a reference to its parent but has no transport of its own. The useful specialization is `base/array_arduino.py`: `ProxyArduinoDevice` (`array_arduino.py:15`) is an `ArduinoDevice` constructed with the parent's existing `_serial_iface` and `_serial_thread_lock`, so all proxies share a single serial port and lock. Each proxy has an `array_index` and computes an offset base variable number: `base = _array_parameter_begin + _array_parameter_period * _array_index` (`array_arduino.py:51`), giving the proxy's parameters non-overlapping `internal_id` ranges on the same microcontroller. `open()`/`close()` on a proxy raise `NotImplementedError` (`array_arduino.py:66`). The parent's `setup` step accepts an `array` dict from the config to instantiate named proxies of a class chosen from `_proxy_types` (`array_arduino.py:98–150`), and `initialize()` recurses into every proxy (`array_arduino.py:176`).

## 6. End-to-end trace: `device["pump"] = 1.5`

1. `BaseDevice.__setitem__("pump", 1.5)` (`device.py:897`) logs, then calls `_check_device_parameter` which verifies the device is open + initialized, the parameter exists, is enabled, and accepts writes.
2. `parameter.validate(1.5)` coerces the type (`device.py:291`) and enforces `min_value`/`max_value`; the parameter's `stop` Event short-circuits the write if set.
3. `self._write(parameter, 1.5)` dispatches to the transport. For `ArduinoDevice` (`device_arduino.py:751`): the thread lock is acquired; the receive buffer is flushed and any junk raises `ParameterCommError`; `_command_write` builds `"S9=1.5\n"`; it is `encode("ascii")`d and written; if `write_acknowledge`, `_receive_acknowledge` blocks for `acknowledge_value` (e.g. `"k"` for the syringe pump at `nrg/syringe_pump.py:364`); finally `_verify_error_register` reads the Arduino's error variable and raises the corresponding typed exception if it is non-zero.
4. On success, `last_known_value` is stored (`device.py:935`) so that parameters with a caching policy of `TRY` return the value on next read without another round-trip.
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

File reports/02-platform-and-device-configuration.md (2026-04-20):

# 02 — Platform Configuration & Device Instantiation

This report traces how robochem_flex is told *which* physical robot it is driving: how platform specs are discovered on disk, how the `Platform` class parses them, how each device is located on the USB/network bus, and how the Streamlit UI feeds a platform choice down into this machinery. The short version: a single `platform_config.json` file describes each named robot (e.g. `Perry`) as a tree of devices, each device maps to a Python class via `device_constructors`, each device is connected either by a *known-device* serial lookup or an `IP`/`host`/`port`, and `PlatformBackend` is the Streamlit-side orchestrator that selects one of these platforms at runtime.

## 1. Platform discovery

Platform specs live in a single JSON file under the `OmniPlatypus` package:

- `Control Software/OmniPlatypus/OmniPlatypus/omniplatypus/config/platform_config.json` (the platform catalogue)
- `Control Software/OmniPlatypus/OmniPlatypus/omniplatypus/config/known_devices.json` (USB/serial ID registry)
- `Control Software/OmniPlatypus/OmniPlatypus/omniplatypus/config/sample_holder_types.json` (vial-holder geometries)
- `Control Software/OmniPlatypus/OmniPlatypus/omniplatypus/config/platform_info.json`
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

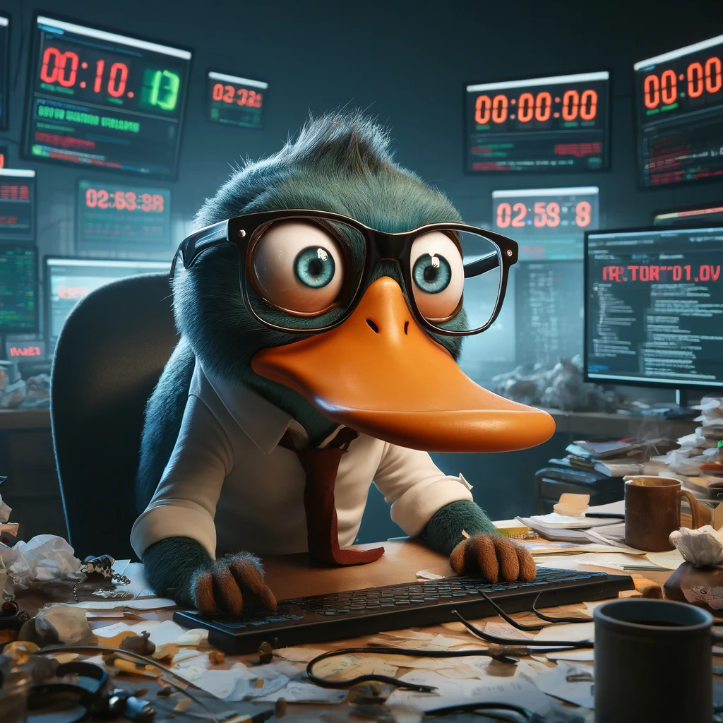
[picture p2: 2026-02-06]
Control Software/utils/platypus.png

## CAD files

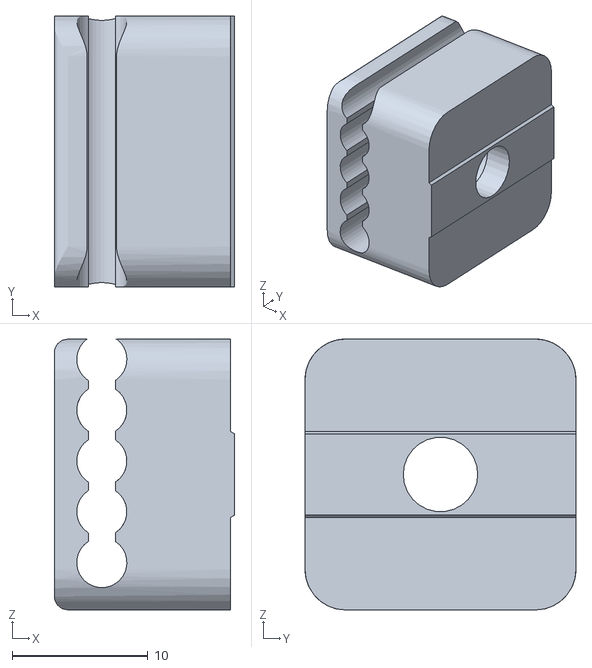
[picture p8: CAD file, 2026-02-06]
Devices/Cartesian Sampler/3D printed models/SP_O8.stl
13.3 x 20.0 x 20.0

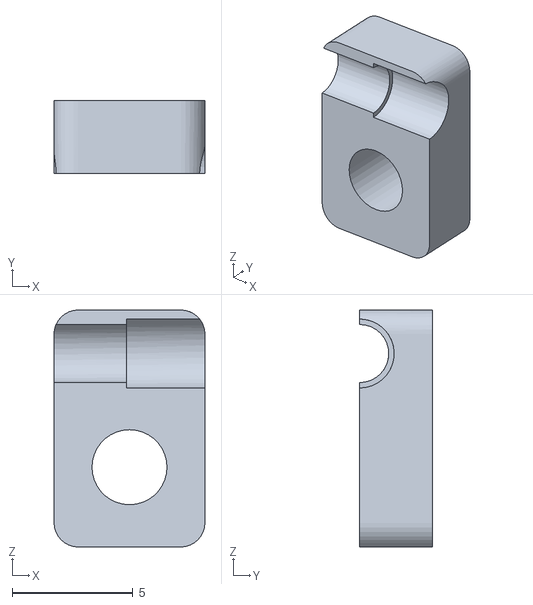
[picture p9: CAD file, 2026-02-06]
Devices/ChromTroller/3d_printed_models/LED_clamp.stl
6.24 x 3.00 x 9.80

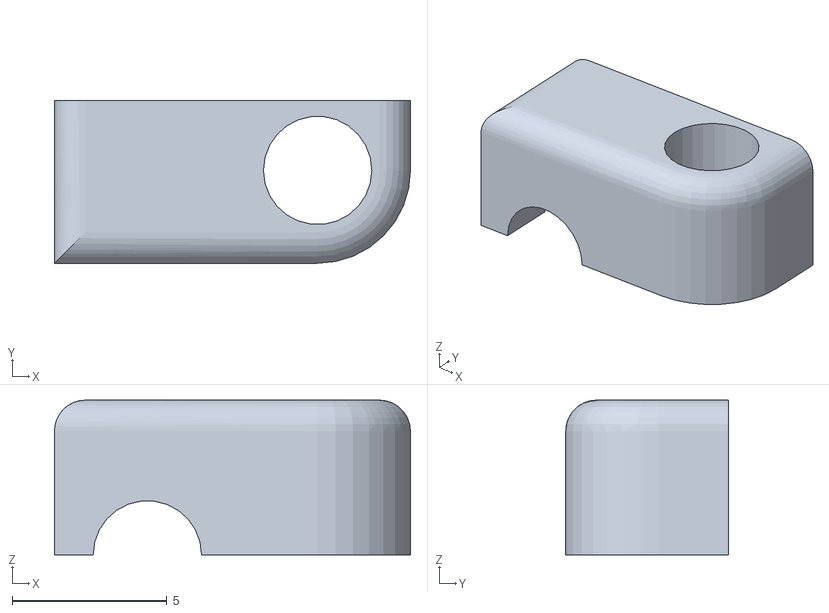
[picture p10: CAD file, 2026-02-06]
Devices/General Purpose Controller/3D printed models/LED_H.stl
11.5 x 5.25 x 5.00

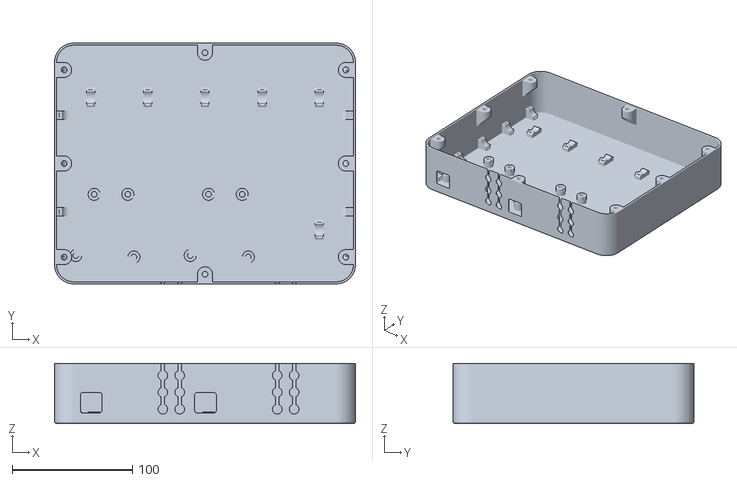
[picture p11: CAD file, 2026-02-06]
Devices/Phase Sensor Controller/3D printed models/BOX.stl
250.0 x 200.0 x 50.0

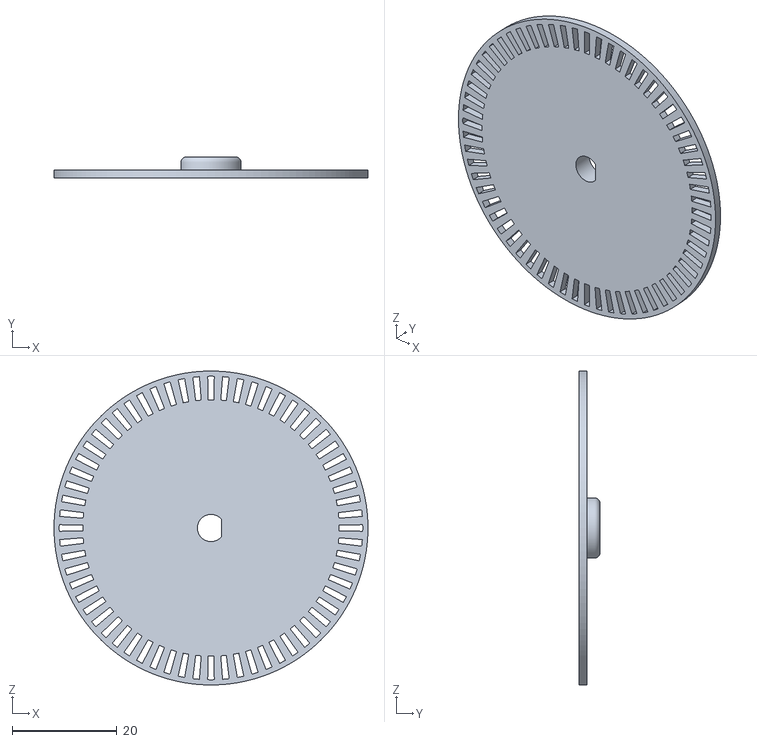
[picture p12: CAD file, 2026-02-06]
Devices/Syringe Pump/3D printed models/SP_OSW.stl
60.0 x 4.00 x 60.0

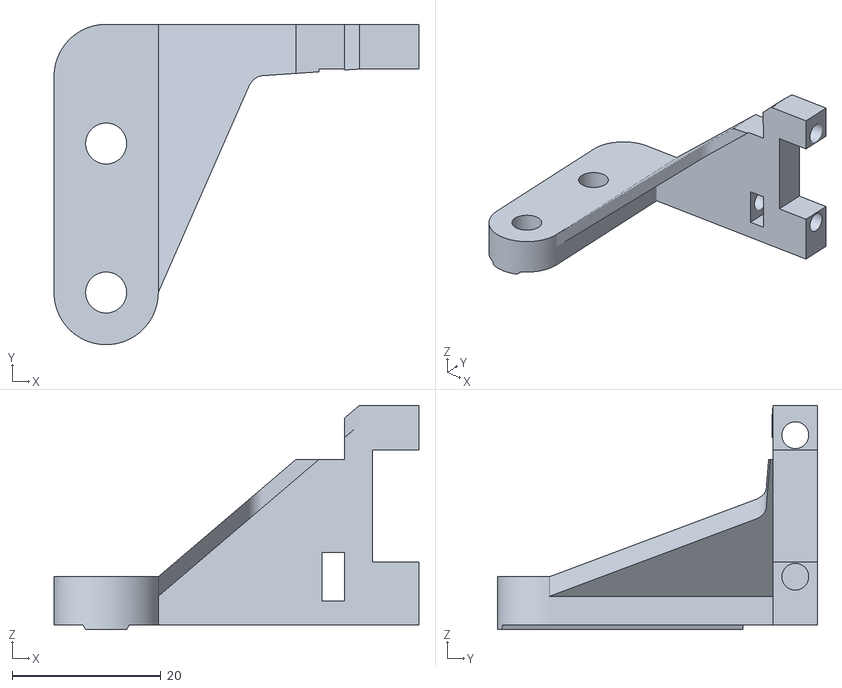
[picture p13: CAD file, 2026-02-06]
Devices/Cartesian Sampler/3D printed models/CS_ESH_Y_R.stl
49.0 x 43.0 x 30.1

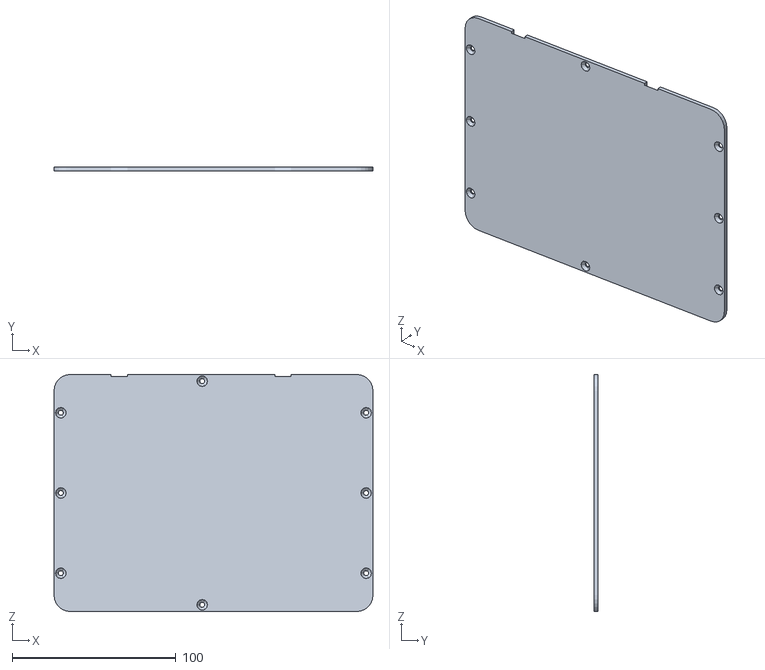
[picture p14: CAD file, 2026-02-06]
Devices/ChromTroller/3d_printed_models/LC_ENCL.stl
194.9 x 2.50 x 144.9

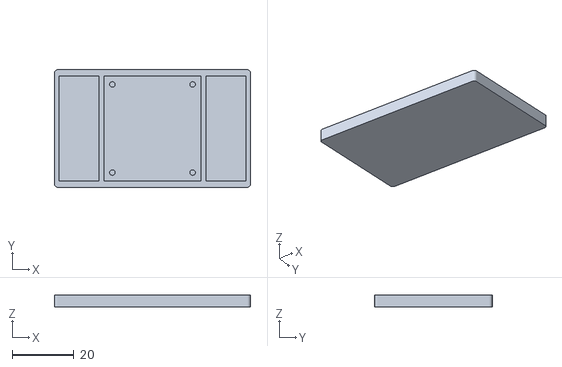
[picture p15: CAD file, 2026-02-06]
Devices/Phase Sensor Controller/3D printed models/SENSOR_HOLDER.stl
63.6 x 38.2 x 4.00

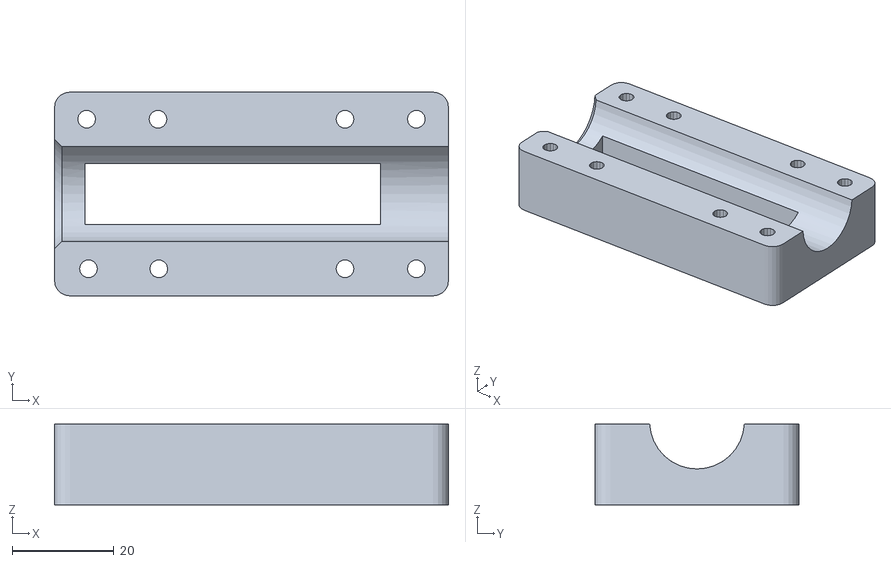
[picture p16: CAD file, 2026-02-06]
Devices/Syringe Pump/3D printed models/SP_BHC_10ML.stl
77.3 x 40.0 x 15.9

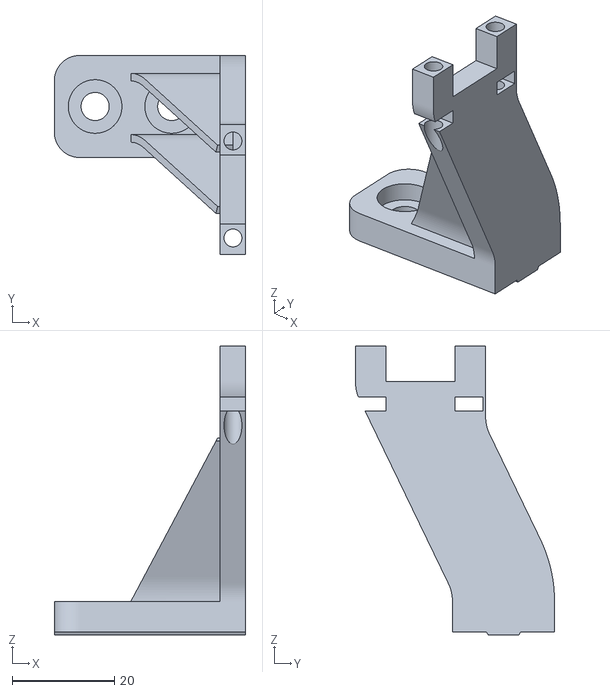
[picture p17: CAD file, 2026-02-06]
Devices/Cartesian Sampler/3D printed models/CS_ESH_X_B.stl
37.5 x 39.0 x 56.6

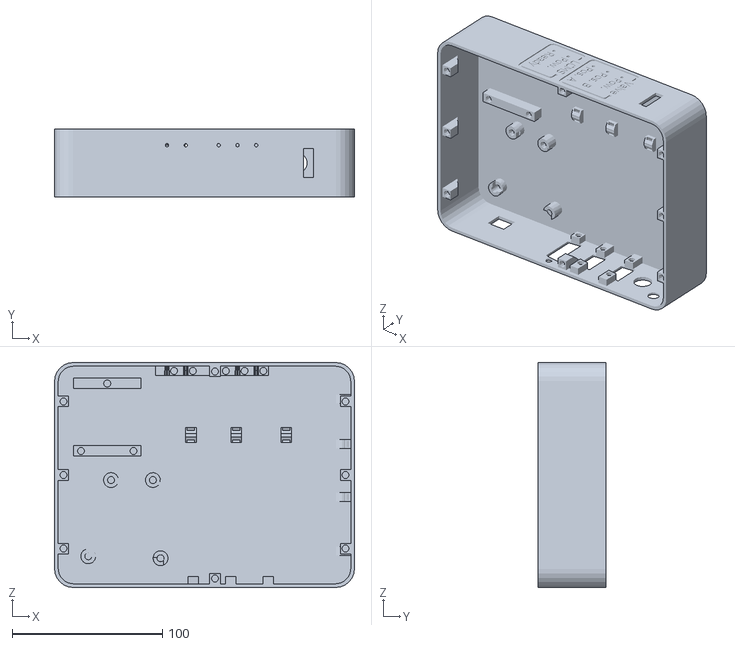
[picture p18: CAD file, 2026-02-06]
Devices/ChromTroller/3d_printed_models/LC_ENC.stl
200.0 x 45.0 x 150.0

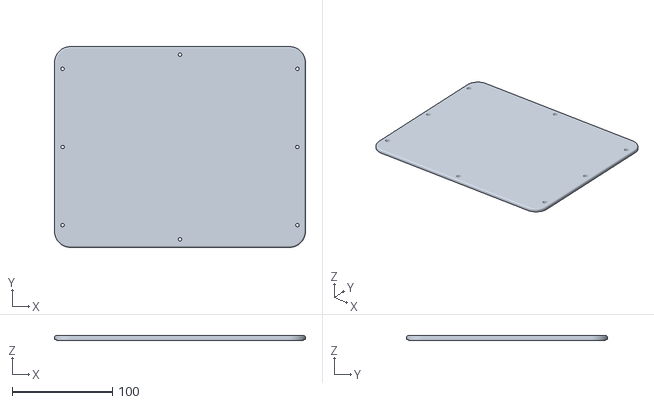
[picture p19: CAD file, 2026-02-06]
Devices/General Purpose Controller/3D printed models/LID.stl
250.0 x 200.0 x 5.00

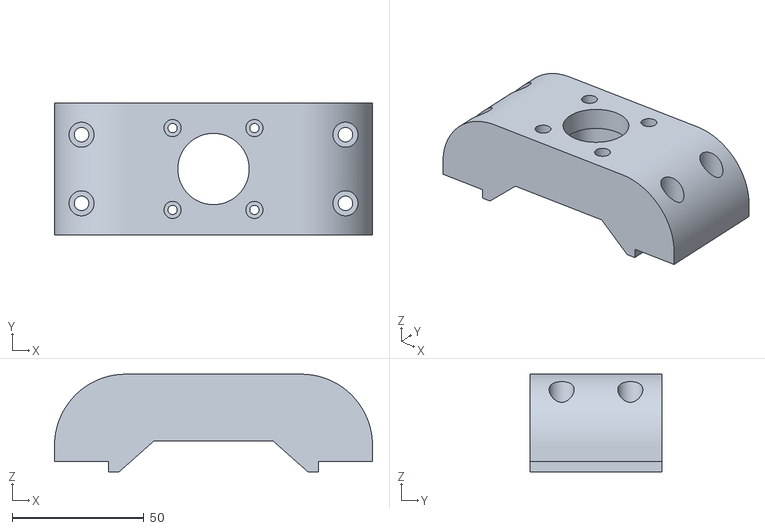
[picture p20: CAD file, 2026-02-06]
Devices/Syringe Pump/3D printed models/SP_SP.stl
120.5 x 50.0 x 37.0

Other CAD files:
Devices/General Purpose Controller/3D printed models/BOX.stl
Devices/Photochemical Reactor Controller/3D printed models/BOX.stl
Devices/Photochemical Reactor Controller/3D printed models/LID.stl
Devices/Cartesian Sampler/3D printed models/CS_AA_B.stl
Devices/Cartesian Sampler/3D printed models/CS_AA_EB.stl
Devices/Cartesian Sampler/3D printed models/CS_AA_EBL.stl
Devices/Cartesian Sampler/3D printed models/CS_AA_G_5p10.stl
Devices/Cartesian Sampler/3D printed models/CS_AA_G_5p15.stl
Devices/Cartesian Sampler/3D printed models/CS_AA_G_5p20.stl
Devices/Cartesian Sampler/3D printed models/CS_AA_G_5p25.stl
Devices/Cartesian Sampler/3D printed models/CS_AA_G_5p30.stl
Devices/Cartesian Sampler/3D printed models/CS_CAA.stl
Devices/Cartesian Sampler/3D printed models/CS_CAA_L.stl
Devices/Cartesian Sampler/3D printed models/CS_CGX_1.stl
Devices/Cartesian Sampler/3D printed models/CS_CGX_2.stl
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

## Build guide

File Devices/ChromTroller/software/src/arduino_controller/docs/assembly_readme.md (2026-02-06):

# ChromTroller Control Box — Assembly Guide

> Hardware build notes for the ChromTroller valve/trigger controller

---

## 📦 Overview

The **ChromTroller control box** is a small microcontroller-based module that:
- Drives a **VICI micro‑electric actuator** to toggle a **two‑position, six‑port** switching valve for sample injection.
- Issues and reads **digital I/O** signals to/from the **Agilent ERI (Enhanced Remote Interface)** on compatible 1290 Infinity II modules to start/stop and monitor runs.
- Interfaces with an **OCB350 phase sensor** for flow-phase monitoring.
- Provides a **fused power path** for the actuator and a front‑panel **power switch**.
- Communicates with the host PC via **USB serial** (Arduino Uno R3).

This ensures the physical injection is **time‑aligned** with UPLC data acquisition, giving reproducible retention times and peak shapes.

---

## 🧰 Bill of Materials (BOM)

| Component | Qty | Supplier | Price (ea) | Part No. |
|---|---:|---|---:|---|
| Arduino Uno R3 | 1 | Conrad | € 16.17 | 191789 |
| Power switch | 1 | Conrad | € 2.30 | 1588060 |
| DC barrel connector 5.5 mm / 2.5 mm | 5 | Conrad | € 1.29 | 1582328 |
| Fuse holder (box) | 1 | Conrad | € 1.49 | 533769 |
| 10 A fuse 5×20 mm (pack of 10) | 1 | ESKA | € 1.49 | 522.627 |
| D‑Sub 9 female | 1 | Conrad | € 0.56 | 1924663‑8J |
| D‑Sub 9 male | 1 | Conrad | € 0.35 | 1303906‑8J |
| D‑Sub 15 female | 1 | Conrad | € 0.64 | 1586473‑8J |
| Module box (print) | 1 | — | — | `LC_ENC.stl` |
| Module box lid (print) | 1 | — | — | `LC_ENCL.stl` |

*Prices as purchased; may change.*

You will also need hookup wire, crimp pins/hoods for D‑Sub connectors, stand‑offs/screws for the Arduino, and heat‑shrink.

---

## 🧱 Enclosure & Front Panel

- 3D‑print `LC_ENC.stl` (box) and `LC_ENCL.stl` (lid).
- Front panel typical cut‑outs: **power switch**, **fuse holder**, **barrel DC jack(s)**, and **status LEDs** (optional).
- Rear panel typical cut‑outs: **D‑Sub‑15** (ERI), **D‑Sub‑9** (valve/aux), and **USB‑B** (Arduino).

> Keep high‑current actuator wiring physically separated from logic lines to reduce noise. Tie grounds at a single star point.

---

## ⚡ Power & Safety

- The actuator is powered via the fused DC input (**5×20 mm, 10 A**). Size the fuse for your actuator’s supply and inrush.
- The **Arduino** is powered via **USB** from the PC. If you power it from the actuator supply, use a regulated 5 V rail and common ground.
- Use **strain relief** for all external cables.
- **Always disconnect power** before rewiring. Verify polarity and fuse rating before first power‑up.

> **Disclaimer:** You are responsible for safe mains/DC wiring and compliance with your local regulations.

---

## 🔌 Interfaces (High‑level)

- **VICI actuator controller:** digital input for **Position A/B** (check your controller’s manual). The control box outputs logic‑level signals from the Arduino to the actuator controller input. 
- **Agilent ERI (Enhanced Remote Interface):** provides digital **Start/Ready/Prepare** lines. The exact pinout **depends on the module**; refer to the Agilent ERI documentation for your model. In practice, a **Sample Prep** method in **OpenLab CDS v2.8** is configured to await a rising edge on a chosen input line (commonly “pin 1”) before starting acquisition.
- **Phase sensor (OCB350):** connect signal and supply per the sensor datasheet. The Arduino reads the sensor for phase monitoring and calibration.

> For detailed wiring schematics and mechanical drawings, see the figures referenced as *Figure S1.66–S1.67* in your documentation folder.

---

## 🧪 Assembly Steps

1. **Prep enclosure**: Deburr prints, test‑fit all panels and connectors.
2. **Mount hardware**: Install the power switch, fuse holder, barrel jack(s), D‑Sub connectors, and Arduino with stand‑offs.
3. **Power wiring**: Wire DC jack → fuse → power switch → actuator supply rail. Keep logic ground connected to the actuator ground at a **single star point**.
4. **ERI harness**: Crimp a D‑Sub‑15 harness to the ERI cable. Map **Start**, **Ready**, **Prepare**, and **GND** per **Agilent ERI** manual for the modules you use.
5. **Actuator harness**: Wire Arduino output pin(s) to actuator controller inputs (through appropriate series resistors or driver stage if required by your actuator). Share **GND**.
6. **Phase sensor**: Provide the sensor supply (per datasheet). Connect signal output to an Arduino digital/analog pin specified in firmware.
7. **Label** all external connectors, add strain relief, close the lid.

---

## 🔧 Firmware & Serial Protocol

Flash the **Arduino Uno R3** with the ChromTroller control firmware (see repository). Connect via **USB serial**.
Commands use human‑readable syntax:

- **Set/Write:** `Sx=y`  
  *Sets variable `x` to value `y` (type depends on variable).*
- **Get/Read:** `Rx`  
  *Reads variable `x` and prints its value.*

> Unless specified, `Sx=y` does not print a response. `Rx` always prints a value.

### Variables

| No. | Access | Type | Description |
|---:|:---:|:---|:---|
| 1 | R/W | `STRING[20]` | Device identifier |
| 2 | R | `INT[0–254]` | Error register `x-y` (type‑value). Resets on read |
| 3 | CMD | `NONE` | Save defaults |
| 4 | CMD | `NONE` | Factory reset |
| 5 | R/W | `INT[0–1]` | **Valve position** (0=A, 1=B). Sends acknowledge when done |
| 6 | CMD | `NONE` | Send **START REQUEST** to UPLC |
| 7 | CMD | `NONE` | Send **STOP** |
| 8 | R | `INT[0–1]` | Read **READY** from UPLC |
| 9 | CMD | `NONE` | **Calibrate** phase sensor |
|10 | R | `INT[0–3]` | Read phase sensor output |
|11 | R | `INT[0–1]` | Read LCMS **power state** |
|12 | R | `INT[0–1]` | Read UPLC **start** signal |
|13 | R | `INT[0–1]` | Read UPLC **prepare** signal |

*If the value type is `NONE`, the equal sign is still required (e.g., `S6=`).*

### Quick Test (Arduino IDE Serial Monitor)

1. Set the valve to A/B: `S5=0` → wait for ack, then `S5=1`  
2. Read READY state: `R8`  
3. Trigger a run (with OpenLab **Sample Prep** method waiting): `S6=`  
4. Stop signal (if configured): `S7=`  
5. Phase sensor: `S9=` to calibrate, then `R10` to read

---

## 🧪 Commissioning with OpenLab CDS v2.8

1. Create/modify a **Sample Prep** method that **waits for external trigger** (e.g., *pin 1* on ERI).  
2. On the instrument PC, start **ChromTroller** and connect the control box via USB.
3. **Queue** runs in OpenLab. They will remain pending until a **START REQUEST** is received.  
4. From ChromTroller (or manual serial), coordinate:
   - Set valve to *LOAD*; fill loop from RoboChem.  
   - Switch to *INJECT* and **immediately** issue `S6=` to start acquisition.  
   - Monitor **READY/START/PREPARE** lines to verify timing.  

This coupling ensures **1.4 µL** effective injection (1 µL loop + valve dead volume) is time‑aligned with data acquisition.

---

## 📎 Notes

- Effective injection volume is ~**1.4 µL** due to loop (1.0 µL, 90 mm × 0.12 mm) plus valve dead volume.
- Keep cable runs short and shielded where possible; reference grounds carefully.
- For ERI pin mapping, **always** consult your module’s manual.

---

## 📄 Figures & Files

- Controller photos & wiring: *Figure S1.67*
- ERI I/O overview: *Figure S1.66*
- Valve sampling/injection: *Figure S1.65*
- General UPLC connectivity: *Figure S1.64*

STLs: `LC_EB.stl`, `LC_EBL.stl` (see `docs/` or `hardware/` folder in repo)

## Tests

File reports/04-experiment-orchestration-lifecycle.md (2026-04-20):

# 04 — Experiment Orchestration Lifecycle

This report documents the experiment-orchestration layer of `robochem_flex`, the module that converts a stream of ML-proposed conditions into physical reactor runs and feeds results back. All code lives under `Control Software/OmniPlatypus/OmniPlatypus/omniplatypus/procedures/experiments/`.

## 1. The `BaseExperiment` contract

`BaseExperiment` (`base_experiment.py:85`) is an `ABC` that models an experiment as a long-lived, thread-based service. Subclasses implement five hook methods; the base class owns the event loop, queues, error classification, and the pairing with an analytical method.

Five lifecycle phases are defined:

1. **`__init__`** (`base_experiment.py:173-215`) validates the requested `analytical_method` against `cls._analytical_methods`, binds an `ExperimentAnalysisCoupler`, checks for duplicate parameter names (`check_duplicate_parameters`, line 217), and builds the public thread interface: five `queue.Queue` objects, a `_stop_event`, a `_resume_event`, and an unstarted `_experiment_thread`. The `Platform` instance is created here but not yet built.
2. **`start` / validate**: `start` (`base_experiment.py:245`) accepts a platform name, a `samples` DataFrame (the vial rack), optional platform-build arguments and constants overrides, and a `queue_update_interval` (default 5 s — the maximum latency between submissions and execution). It raises `RuntimeError` if a previous thread is still alive and launches `Thread(target=self._run, …, daemon=False)`.
3. **`_procedure_build`** (`base_experiment.py:638-667`) is the one-shot "prime" phase on the experiment thread: it calls `self._platform.build(**args)`, merges `platform_config.json` constants with any overrides via `_merge_platform_constants`, and instantiates `self._analytical_method` from `ExperimentAnalysisCoupler.analysis_class`, attaching the analytical device from the platform.
4. **`_procedure_prepare`** is an abstract (`base_experiment.py:679`) "clean + check" run before the first iteration. `ChemicalReaction._procedure_prepare` (`chemistry.py:323`) connects the injection port, primes both syringe pumps in parallel via `run_all`, and triggers `_procedure_cleanup` if the constant `cleaning.clean_on_start` is true.
5. **`_procedure_cleanup`** (`base_experiment.py:711`) runs after *every* iteration; `_procedure_shutdown` (`base_experiment.py:720`) runs once inside the `finally` of `_run`, calling `self._platform.clear()` to power down devices.

`submit_run` (line 442) first calls `check_run_parameters` (line 355), which rejects missing required parameters, unknown extra parameters, and parameters of the wrong subtype — catching errors *before* any pumps move.

## 2. Threading and queueing

The orchestration layer is a single-producer / single-consumer model wrapped around one experiment thread. Five queues are the only allowed cross-thread communication (`base_experiment.py:199-203`):

| Queue | Direction | Purpose |
|---|---|---|
| `_run_requests_queue` | public → thread | new `{"ID", "parameters"}` dicts from `submit_run` |
| `_run_results_queue` | thread → public | `RunResult` objects retrievable via `get_result` |
| `_user_action_queue` | thread → public | `UserActionRequest`s emitted when a platform/unit task needs human help |
| `_action_request_queue` | public → thread | `UserAction` resolutions from the GUI |
| `_samples_queue` | thread → public | snapshots of the vial-rack DataFrame |

Two `threading.Event`s drive flow control: `_stop_event` (shutdown) and `_resume_event` (pause/resume). The public `pause()` (line 307) flushes the samples queue, clears `_resume_event`, and blocks on `_samples_queue.get()`; the thread, on seeing a cleared resume-event, pushes a samples snapshot and waits (see `_run` below). `stop()` (line 336) additionally sets `_stop_event` and joins the thread.

The main thread body, `_run` (`base_experiment.py:761-874`), wraps everything in a `while not self._stop_event.is_set() and restart_platform:` outer loop, a `try / finally` that *always* calls `_procedure_shutdown`, and an inner run-consumer loop:

```python
while not self._stop_event.is_set():
    self._process_user_actions()
    if not self._resume_event.is_set():
        self._resume_event.wait(self._queue_update_interval)
        continue
    try:
        run_request = self._run_requests_queue.get(
            block=True, timeout=self._queue_update_interval)
    except Empty:
        continue
    # … process run …
```
(`base_experiment.py:792-806`)

Concurrency inside a single iteration is used for three things: (a) running pump priming and slug-preparation steps in parallel via `run_all(*threads)` (see `chemistry.py:330-333, 1173-1180`); (b) background monitoring threads (reactor phase monitor, light-current monitor, temperature monitor); (c) user-action pumps handled by `_wait_for_user_action` (line 589), where the experiment thread blocks on `self._stop_event.wait(interval)` and polls `_process_user_actions` until the GUI resolves the issue or `stop()` is called.

Cancellation is cooperative: `stop()` calls `flush_queue(self._samples_queue)` then `self._stop_event.set()`. The long-blocking queues all use `timeout=self._queue_update_interval`, so the loop notices the stop event within ~5 s. A stop does *not* kill a running iteration — it lets the current slug finish, then falls out of the loop into `_procedure_shutdown`.

## 3. One iteration end-to-end

`_run_procedure_experiment` (`base_experiment.py:727-759`) brackets a single iteration:

```python
run_result = RunResult(run_id)
conditions = self._conditions_from_parameters(parameters)
recipe = self._recipe_from_parameters(parameters)
try:
    self._procedure_experiment(run_result, conditions, recipe)
except Exception as error:
    run_result.exception = error
    run_result.success = False
finally:
    self._update_parameters(parameters, conditions, recipe)
    run_result.parameters = parameters
    return run_result
```

`_conditions_from_parameters` (line 876) filters out `ChemicalParameter`s and fills in defaults from `_optional_parameters`. `_recipe_from_parameters` (line 902) takes the chemical parameters and builds a `list[RecipeComponent]`; it enforces the rule that *exactly one* chemical is given as an absolute concentration (the limiting reagent) and the rest as equivalents, or that *all* are concentrations. Equivalents are multiplied by the limiting concentration on line 954. Finally `_update_parameters` (line 981) back-writes any values modified in-flight (e.g. rounded light intensity, measured residence time) into the parameter list so the ML sees the *actual* executed values.

A sequence diagram of one iteration on `PhotochemicalReaction` with an NMR analytical coupling:

```mermaid
sequenceDiagram
    participant ML as ML backend
    participant Q as _run_requests_queue
    participant T as experiment thread (_run)
    participant R as reactor-monitor thread
    participant P as Platform + devices
    participant AN as AnalyticsTemplate

    ML->>Q: submit_run(id, params)
    T->>Q: get(block, timeout=5s)
    T->>T: _conditions_from_parameters / _recipe_from_parameters
    T->>P: GenerateComposition.run (sampler recipe)
    T->>P: _reactor_prepare (set light / temperature)
    T-->>R: Thread(_reactor_wait_until_ready)
    T->>P: PrepareReactionSlug / MixSlugSampler
    T->>P: Inject + SlugQualityCheck
    T->>R: join(timeout=reactor_timeout)
    T-->>R: Thread(_reactor_monitoring_target) (phase log)
    T->>P: PumpVolume(reaction_volume, reaction_flowrate)
    T->>R: stop / join monitor
    T->>P: PumpUntilPhaseChange(analysis_phase_sensor)
    T->>AN: sample_loading(True) + analyse(conditions, recipe)
    AN-->>T: result dict
    T->>P: PumpSample(collection_vial) or dump
    T->>T: RunResult(success, result, parameters, collection_vial_id)
    T->>ML: _run_results_queue.put(result)
    T->>P: _procedure_cleanup
```

## 4. Reaction subclasses

All three subclasses override only the "reactor" hooks — the slug-preparation / injection / analysis / cleanup flow in `ChemicalReaction._procedure_experiment` is shared.

**`ChemicalReaction`** (`chemistry.py:72`) is the heavy lifter. Its `_procedure_experiment` (line 478) does, in order: parameter coercion and constant lookup (sampling/reaction/analysis sections of `_platform_constants`), flowrate calculation `reaction_flowrate = reactor_volume / residence_time` (line 557), slug composition via `GenerateComposition.run`, background `_reactor_wait_until_ready` thread, slug preparation (`PrepareReactionSlug`, `MixSlugSampler`), injection (`Inject.run`), slug-quality check (with `BadSlugQualityError` vs `CloggingError` distinction at line 908-918), the timed reaction pump (`PumpVolume(reaction_volume, reaction_flowrate)`, line 940), reactor-output phase monitoring, optional slug verification (`_move_slug_and_verify`, line 436), optional analytical device loading and `self._analytical_method.analyse(conditions, recipe)` (line 1022), and either collection into a vial or dump to waste. It defines five supported analytical couplings — `Human`, `NMR`, `NMR_dummy`, `UPLC`, `Raman` — in `_analytical_methods` at line 97.

**`PhotochemicalReaction`** (`photochemistry.py:51`) adds one required parameter (`light_intensity`, quantised to 25 % steps), one device (`Light_Array`), and overrides the three reactor hooks: `_reactor_prepare` sets light via `SetLightSourceIntensity.run` (line 125), `_reactor_standby` turns it off (line 150), `_reactor_wait_until_ready` is a no-op (light response is effectively instant). Its `_procedure_build` additionally starts a `ContinuousMonitoring` thread on the light array's `current` parameter (30 s update; line 104-109) and its `_procedure_shutdown` stops that thread via `self._stop_monitoring.set()`.

**`ThermochemicalReaction`** (`thermochemistry.py:29`) adds `temperature` (required) and `stirring` (optional), requires `heating_plate_IKA`, and optionally binds a cooling `Fan`. `_reactor_prepare` calls `SetReactorTemperature.run` (line 117). `_reactor_wait_until_slug_can_be_prepared` (line 121) gates slug preparation so that a prepared slug never sits waiting on a cold/hot reactor: if current temperature is >5 °C over target it kicks the fan; if >20 °C under it blocks. `_reactor_wait_until_ready` calls `CheckReactorTemperature.run(..., stability_duration=30.0, tolerance=2.5)`. `_reactor_standby` sets target to 0 and turns the fan on. Temperature is continuously monitored via `ContinuousMonitoring` on `actual_sensor_temperature` (line 96).

## 5. `ExperimentAnalysisCoupler`

`ExperimentAnalysisCoupler` (`base_experiment.py:52-82`) is a plain record with three fields: `analysis_class` (a `Type[AnalyticsTemplate]` such as `NMRAnalysis`, `HPLCAnalysis`, `AnalyticsRaman`, `DummyNMRAnalysis`, or `None` for human analysis), `analytical_device` (the device name in `platform_config.json` to be passed to the analysis constructor), and `platform_constants_key` (the sub-key under `constants.analysis` where volumes and offsets for that coupling live). Each experiment class exposes a dict `_analytical_methods: dict[str, ExperimentAnalysisCoupler]`. The user picks one by name at `__init__`, `_procedure_build` instantiates `analysis_class(analytical_device=…, processing_method=None, storage_root=…)` (`base_experiment.py:663`), and per-iteration the analysis plugs in via `self._analytical_method.sample_loading(enable=…)` and `self._analytical_method.analyse(conditions, recipe)` (`chemistry.py:1013-1027`).

## 6. `RunResult`

`RunResult` (`experiment_parameters.py:222-267`) is the entire payload returned to the ML backend:

```python
class RunResult:
    run_id: str
    result: Any                                  # dict returned by analyse()
    success: bool                                # True only if full flow reached end
    parameters: list[ExperimentalParameter]      # *actual* executed values
    collection_vial_id: str | None
    exception: Exception | None
```

`success` is set to `True` only on the last line of `_procedure_experiment` (`chemistry.py:1099-1106`); if the analysis dict contains a `"pass"` key that overrides it. `parameters` are back-written via `_update_parameters` so measured fields (`measured_slug_volume`, `measured_residence_time`) end up in the result. The convenience `get_param_by_name` (line 252) lets the ML frontend pull one parameter by name; each returned parameter is a deepcopy.

## 7. Error handling and recovery

Errors are captured inside `_run_procedure_experiment`'s `try/except Exception` block and stuffed into `run_result.exception` — the running iteration always returns a result. The outer `_run` loop (`base_experiment.py:828-862`) then classifies the exception:

- `BadSlugQualityError`, `ValueError`: swallow, keep running, continue with the next submitted run.
- `DeviceCommunicationError`, `DeviceTimeoutError`, `ParameterCommError`, `ParameterTimeoutError`, `ParameterAcknowledgeError`, `ParameterNotRunningError`, `SoftLimitError`, `HardLimitError`, `AlarmLockError`: set `restart_platform = True` and `break` out of the inner loop — the outer loop then rebuilds the platform (`_procedure_build` + `_procedure_prepare`) and resumes processing the queue.
- Anything else: log and re-raise from `_run`, which unwinds to `_procedure_shutdown` via the `finally`.

Per-iteration, `_procedure_cleanup` still runs after a failed run (note the inner `else` branch calls cleanup only on success; on device errors the break skips cleanup but `_procedure_build` on restart will re-prepare). The `BadSlugQualityError`-vs-`CloggingError` split at `chemistry.py:908-918` shows finer granularity: <=1 phase change implies a clogged line (raised as `CloggingError` which *does* restart the platform), otherwise a slug failure (retryable without restart, with `_discard_slug=True` triggering a lighter cleanup variant). User-resolvable conditions (missing vials, exhausted reagents) go through `_wait_for_user_action` (line 589), which blocks the run indefinitely — the ML sees only that the result takes longer, not that an error occurred — until `UserSetSamples` arrives via `submit_user_action`.

The net effect: the ML backend submits a run, waits on `get_result(timeout=…)`, and receives a `RunResult` whose `.success` / `.exception` fields tell it how to score the proposal. The platform keeps churning until `stop()` is called, self-healing through device glitches and surfacing only genuinely unrecoverable faults.

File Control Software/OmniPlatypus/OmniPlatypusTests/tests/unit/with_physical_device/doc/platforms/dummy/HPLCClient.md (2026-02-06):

# Chromtroller HPLC Client usage

    Connect to Chromtroller server via socket interface and access HPLC device.
    
## Parameters:

| Name | Access | Type | Description | Values |
|---|---|---|---|---|
| **run_info** | WRITE ONLY | dict | Info about the run to be logged by the server| | 
| **analysis_parameters** | WRITE ONLY | HPLCProcessingSettings | Settings to use for automatic chromatogram processing| | 
| **rt_target** | WRITE ONLY | float | Sets the target retention time for automatic chromatogram processing| | 
| **rt_tolerance** | WRITE ONLY | float | Sets the allowed tolerance in rt for automatic chromatogram processing| | 
| **valve_position** | WRITE ONLY | ValvePosValue | Set valve position. Either 'FILL' or 'INJECT'| - FILL -> FILL, - INJECT -> INJECT, | 
| **acquisition** | WRITE ONLY | ParameterValueRunHplc | Starts the acquisition procedure to analyse a sample stored in the sample loop| | 
| **analysis_result** | READ ONLY | dict | Starts the analysis procedure and returns the results| | 

## Setup options:
| Name | Required | Type | Description |
|---|---|---|---|

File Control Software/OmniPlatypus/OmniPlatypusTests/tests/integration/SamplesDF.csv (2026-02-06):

SampleID | Conc_A | Volume | Type | Sampler | Holder | Position | Add
Stock1 | 20 | 1200 | Stock | Sampler_cnc | holder_left | A1 | 0
Stock2 | 20 | 1200 | Stock | Sampler_cnc | holder_left | B1 | 0
Stock3 | 20 | 1200 | Stock | Sampler_cnc | holder_left | C1 | 0
Stock4 | 20 | 1200 | Stock | Sampler_cnc | holder_left | D1 | 0
Stock5 | 20 | 1200 | Stock | Sampler_cnc | holder_left | E1 | 0
Stock6 | 20 | 1200 | Stock | Sampler_cnc | holder_left | F1 | 0
Stock7 | 20 | 1200 | Stock | Sampler_cnc | holder_left | A2 | 0
Stock8 | 20 | 1200 | Stock | Sampler_cnc | holder_left | B2 | 0
Stock9 | 20 | 1200 | Stock | Sampler_cnc | holder_left | C2 | 0
Solvent1 | 0 | 1200 | Solvent | Sampler_cnc | holder_left | D2 | 0
Solvent2 | 0 | 1200 | Solvent | Sampler_cnc | holder_left | E2 | 0
Solvent3 | 0 | 1200 | Solvent | Sampler_cnc | holder_left | F2 | 0
Solvent4 | 0 | 1200 | Solvent | Sampler_cnc | holder_left | A3 | 0
Solvent5 | 0 | 1200 | Solvent | Sampler_cnc | holder_left | B3 | 0
Solvent6 | 0 | 1200 | Solvent | Sampler_cnc | holder_left | C3 | 0
Solvent7 | 0 | 1200 | Solvent | Sampler_cnc | holder_left | D3 | 0
Solvent8 | 0 | 1200 | Solvent | Sampler_cnc | holder_left | E3 | 0
Solvent9 | 0 | 1200 | Solvent | Sampler_cnc | holder_left | F3 | 0
Dilution_005_1 | 0 | 0 | Sample | Sampler_cnc | holder_left | A4 | 0
Dilution_005_2 | 0 | 0 | Sample | Sampler_cnc | holder_left | B4 | 0
Dilution_005_3 | 0 | 0 | Sample | Sampler_cnc | holder_left | C4 | 0
Dilution_020_1 | 0 | 0 | Sample | Sampler_cnc | holder_left | D4 | 0
Dilution_020_2 | 0 | 0 | Sample | Sampler_cnc | holder_left | E4 | 0
Dilution_020_3 | 0 | 0 | Sample | Sampler_cnc | holder_left | F4 | 0
Dilution_050_1 | 0 | 0 | Sample | Sampler_cnc | holder_left | A5 | 0
Dilution_050_2 | 0 | 0 | Sample | Sampler_cnc | holder_left | B5 | 0
Dilution_050_3 | 0 | 0 | Sample | Sampler_cnc | holder_left | C5 | 0
Dilution_070_1 | 0 | 0 | Sample | Sampler_cnc | holder_left | D5 | 0
Dilution_070_2 | 0 | 0 | Sample | Sampler_cnc | holder_left | E5 | 0
Dilution_070_3 | 0 | 0 | Sample | Sampler_cnc | holder_left | F5 | 0
Dilution_120_1 | 0 | 0 | Sample | Sampler_cnc | holder_left | A6 | 0
Dilution_120_2 | 0 | 0 | Sample | Sampler_cnc | holder_left | B6 | 0
Dilution_120_3 | 0 | 0 | Sample | Sampler_cnc | holder_left | C6 | 0
Dilution_180_1 | 0 | 0 | Sample | Sampler_cnc | holder_left | D6 | 0
Dilution_180_2 | 0 | 0 | Sample | Sampler_cnc | holder_left | E6 | 0
Dilution_180_3 | 0 | 0 | Sample | Sampler_cnc | holder_left | F6 | 0

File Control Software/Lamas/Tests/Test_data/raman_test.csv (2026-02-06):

 | Rshift | 20240418_003416_909
0 | -27.28431624923972 | 11.259375000000546
1 | -24.137810440559743 | 32.384375000000546
2 | -20.992855305911224 | 0.884375000000091
3 | -17.849449699264277 | -9.365624999999909
4 | -14.709577990190768 | 11.634375000000091
5 | -11.570259296931825 | 13.009375000000546
6 | -8.432485724277697 | 38.63437500000009
7 | -5.297247424298958 | -10.490624999999909
8 | -2.163550990117585 | 37.676041666666606
9 | 0.9686047153885033 | 0.6343750000005457
10 | 4.098230996806874 | -12.990624999999454
11 | 7.226319793020991 | 57.717708333333576
12 | 10.351883377225125 | 25.842708333333576
13 | 13.47690108550667 | 51.051041666666606
14 | 16.599396813964887 | 5.801041666666606
15 | 19.71937314585023 | 47.17604166666706
16 | 22.838806501711186 | 108.00937500000055
17 | 25.95572368194708 | 87.0510416666666
18 | 29.070127261761424 | 83.75937500000055
19 | 32.18399075351902 | 76.71770833333358
20 | 35.29534385461391 | 29.842708333333576
21 | 38.40517363784589 | 84.96770833333358
22 | 41.51249719788232 | 85.84270833333358
23 | 44.61928418112446 | 73.00937500000055
24 | 47.72258507542738 | 85.8010416666666
25 | 50.82535162225085 | 111.38437500000055
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

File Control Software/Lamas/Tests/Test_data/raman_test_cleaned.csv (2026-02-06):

R_shift | 20240418_003416_909
-27.28431624923972 | 5.833881348098343
-24.137810440559743 | 7.2608292119917675
-20.992855305911224 | 8.200313170077948
-17.849449699264277 | 8.652519662514672
-14.709577990190768 | 8.6176350474566
-11.570259296931823 | 8.095845596533227
-8.432485724277697 | 4.060759429204866
-5.297247424298958 | 7.436149308826971
-2.163550990117585 | 7.822388922818121
0.9686047153885032 | 10.331637754807229
4.098230996806874 | 10.054785585194935
7.226319793020991 | 7.822954252362763
10.351883377225125 | 14.393164453899363
13.47690108550667 | 18.948028297910348
16.599396813964887 | 28.773709065209452
19.71937314585023 | 37.592862024051605
22.838806501711183 | 36.305711406930634
25.95572368194708 | 40.33673600884765
29.070127261761424 | 42.36821488581046
32.18399075351902 | 44.293339651798526
35.29534385461391 | 38.873472102206705
38.40517363784589 | 34.430209169171675
41.51249719788232 | 43.00107544937675
44.61928418112446 | 46.608353625674404
47.72258507542738 | 50.46033406993867
50.82535162225085 | 47.060193650315284
53.926601392168415 | 43.20777119275502
57.02437225535298 | 37.66113531433583
60.12063048208482 | 35.03771149563056
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

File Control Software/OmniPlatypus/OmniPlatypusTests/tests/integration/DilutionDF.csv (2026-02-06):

DIlutionID | SolventID | StockID | SolventVol | StockVol | EndVol | Stock_conc | DilutionConc
Dilution_005_1 | Solvent1 | Stock1 | 487.5 | 12.5 | 500 | 20 | 0.5
Dilution_005_2 | Solvent1 | Stock1 | 487.5 | 12.5 | 500 | 20 | 0.5
Dilution_005_3 | Solvent2 | Stock2 | 487.5 | 12.5 | 500 | 20 | 0.5
Dilution_020_1 | Solvent2 | Stock2 | 450 | 50 | 500 | 20 | 2
Dilution_020_2 | Solvent3 | Stock3 | 450 | 50 | 500 | 20 | 2
Dilution_020_3 | Solvent3 | Stock3 | 450 | 50 | 500 | 20 | 2
Dilution_050_1 | Solvent4 | Stock4 | 375 | 125 | 500 | 20 | 5
Dilution_050_2 | Solvent4 | Stock4 | 375 | 125 | 500 | 20 | 5
Dilution_050_3 | Solvent5 | Stock5 | 375 | 125 | 500 | 20 | 5
Dilution_070_1 | Solvent5 | Stock5 | 325 | 175 | 500 | 20 | 7
Dilution_070_2 | Solvent6 | Stock6 | 325 | 175 | 500 | 20 | 7
Dilution_070_3 | Solvent6 | Stock6 | 325 | 175 | 500 | 20 | 7
Dilution_120_1 | Solvent7 | Stock7 | 200 | 300 | 500 | 20 | 12
Dilution_120_2 | Solvent7 | Stock7 | 200 | 300 | 500 | 20 | 12
Dilution_120_3 | Solvent8 | Stock8 | 200 | 300 | 500 | 20 | 12
Dilution_180_1 | Solvent8 | Stock8 | 50 | 450 | 500 | 20 | 18
Dilution_180_2 | Solvent9 | Stock9 | 50 | 450 | 500 | 20 | 18
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

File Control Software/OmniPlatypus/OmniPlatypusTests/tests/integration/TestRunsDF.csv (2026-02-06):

residence_time | light_intensity | slug_volume | rinse | bubble_volume | intercomponent_bubble_volume | mix_before_injection | mix_after_injection | collection_vial | flowrate_sampling | slug_preparation | sampling | premix
30.0 | 0.0 | 500.0 | 1.0 | 50.0 | 0.2 | 6.0 | 0.0 | C_A1 | 0.25 | middle | direct | 0.4
30.0 | 0.0 | 500.0 | 1.0 | 50.0 | 0.2 | 6.0 | 0.0 | C_A2 | 0.25 | middle | direct | 0.2
30.0 | 0.0 | 500.0 | 1.0 | 50.0 | 0.2 | 6.0 | 0.0 | C_A3 | 0.25 | middle | direct | 0.1
30.0 | 0.0 | 500.0 | 1.0 | 50.0 | 0.2 | 6.0 | 0.0 | C_A4 | 0.25 | middle | direct | 0.05
30.0 | 0.0 | 500.0 | 1.0 | 50.0 | 0.2 | 6.0 | 0.0 | C_B1 | 0.25 | middle | direct | 0.4
30.0 | 0.0 | 500.0 | 1.0 | 50.0 | 0.2 | 6.0 | 0.0 | C_B2 | 0.25 | middle | direct | 0.2
30.0 | 0.0 | 500.0 | 1.0 | 50.0 | 0.2 | 6.0 | 0.0 | C_B3 | 0.25 | middle | direct | 0.1
30.0 | 0.0 | 500.0 | 1.0 | 50.0 | 0.2 | 6.0 | 0.0 | C_B4 | 0.25 | middle | direct | 0.05
30.0 | 0.0 | 500.0 | 1.0 | 50.0 | 0.2 | 6.0 | 0.0 | C_C1 | 0.25 | middle | direct | 0.4
30.0 | 0.0 | 500.0 | 1.0 | 50.0 | 0.2 | 6.0 | 0.0 | C_C2 | 0.25 | middle | direct | 0.2
30.0 | 0.0 | 500.0 | 1.0 | 50.0 | 0.2 | 6.0 | 0.0 | C_C3 | 0.25 | middle | direct | 0.1
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

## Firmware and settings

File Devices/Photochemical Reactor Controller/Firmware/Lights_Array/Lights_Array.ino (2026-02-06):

/*
 Arduino UNO light intensity controller.
 With some external components, generates 0-10v smooth analog signals which can control the light intensity for any light sources supporting this
 feature. One Arduino can control up to 4 light sources individually.
 The controller has been tested with PR160L light sources.

 Serial Communication:

   Sx=y
   Set variable x to value y. Variable number are integer, values are signed floating point.
   Rx
   Read variable x and print its value to serial.

 Variable list:
   number | acccess     | type        | description
   -------|-------------|-------------|--------------------------
    0     | RESERVED    |             | Serial.parseInt returns 0 on error.
    1     | READ/WRITE  | STRING [20] | Device identifier.
    2     | READ_ONLY   | INT[0-254]  | Number of subdevices.
    3     | READ/WRITE  | INT[0-1]    | Enable power source for lights (all lights).
    4     | READ_ONLY   | INT[0-5000] | Power source measured current (all lights) [mA].
    5     | READ/WRITE  | INT[0-1024] | Current measure offset.
    6     | READ/WRITE  | INT         | Current measure proportional conversion factor.
    7     | READ_ONLY   | FLOAT       | Power source measured voltage (all lights) [V].
    8     | READ/WRITE  | FLOAT       | Voltage measure proportional conversion factor.
    9     | READ_ONLY   | INT-INT     | Error register 'x-y' x = error type, y = error value. Is reset upon reading.
   10     | COMMAND     | NONE        | Save defaults.
   11     | COMMAND     | NONE        | Factory Reset.

 Array Variable list (repeats for each light source):
   Variable number = 20+10*subdevice_id+index
   index | acccess     | type        | description
   ------|-------------|-------------|-------------------------
    0    | READ/WRITE  | INT[0-100]  | Light intensity [%].
    1    | READ/WRITE  | FLOAT       | Calibration value.
    2    | READ/WRITE  | FLOAT       | PID Proportional constant.
    3    | READ/WRITE  | FLOAT       | PID Integral constant.
    4    | READ/WRITE  | FLOAT       | PID Derivative constant.

 Error codes:
   type  |  description    | value
   ------|-----------------|--------------
   0     | No error        | Undefined
   1     | Serial error    | Variable number which gave the issue
   2     | Subdevice error | See Analog_out.h

 Hardware connections (Arduino UNO board):
   Todo

 Libraries:
   no external libraries.

 by Simone Pilon <s.pilon at uva.nl> - Noël Research Group - 2024
*/

// todo ADD PID values to eeprom.
// todo add errors to devices (try to detect if 16v power is on).

#include <math.h>
#include <EEPROM.h>
#include "Device_id.h"
#include "Analog_out.h"

// Error codes (type)
#define ERROR_NO_ERROR 0	// No error.
#define ERROR_SERIAL 1     // error value is variable number from error.
#define ERROR_ANALOGOUT 2  // See Analog_out.h

// Other
#define MAX_SUBDEVICES 4
#define SERIAL_ARRAY_BEGIN 20  // First array command in serial
#define SERIAL_ARRAY_PERIOD 10 // Number of serial commands per sensor

// General pins
#define SSRELAY_PIN 4          // Activate solid state relay (lights power enable).
#define CURRENT_SENS_PIN 19    // Measure power current.
#define VOLTAGE_SENS_PIN 18    // Measure power voltage.

// Subdevices pins
// Do not use 9, 10 as pwm out (Timer 1 used for timing),
#define SUB0_OUTPUT_PIN 5
#define SUB0_INPUT_PIN 14	// AN0
#define SUB1_OUTPUT_PIN 6
#define SUB1_INPUT_PIN 15	// AN1
#define SUB2_OUTPUT_PIN 11
#define SUB2_INPUT_PIN 16	// AN2
#define SUB3_OUTPUT_PIN 3
#define SUB3_INPUT_PIN 17	// AN3

// EEPROM
#define EEPROM_ADDRESS_CHECK 0	// 1 byte char
#define DEFAULT_CHECK 42
#define EEPROM_ADDRESS_ID 1	// 20 bytes char[]
#define DEFAULT_ID "LIGHTS_0"
#define EEPROM_ADDRESS_CURRENT_OFFSET 30	// 2 byte int
#define DEFAULT_CURRENT_OFFSET 509
#define EEPROM_ADDRESS_CURRENT_CAL 32		// 2 byte int
#define DEFAULT_CURRENT_CAL 37
#define EEPROM_ADDRESS_VOLTAGE_CAL 40		// 4 byte float
#define DEFAULT_VOLTAGE_CAL 0.0185
// +-- Subdevices (repeats)
#define EEPROM_ADDRESS_SD_CAL 44	// 4 byte float
#define EEPROM_ADDRESS_SD_P 48	// 4 byte float
#define DEFAULT_SD_P 0.80
#define EEPROM_ADDRESS_SD_I 52	// 4 byte float
#define DEFAULT_SD_I 0.04
#define EEPROM_ADDRESS_SD_D 56	// 4 byte float
#define DEFAULT_SD_D 0.02
#define EEPROM_PERIOD_SD 16

// Others
#define TIMER_COUNTER 25000	// Set for 100mS interval updates

// Global variables
uint8_t error_type = 0;
uint8_t error_value = 0;
bool power_enable = false;
int current_offset = DEFAULT_CURRENT_OFFSET;
int current_cal = DEFAULT_CURRENT_CAL;
float voltage_cal = DEFAULT_VOLTAGE_CAL;
AnalogOut subdevices[MAX_SUBDEVICES] = {
									AnalogOut( SUB0_OUTPUT_PIN, SUB0_INPUT_PIN),
									AnalogOut( SUB1_OUTPUT_PIN, SUB1_INPUT_PIN),
									AnalogOut( SUB2_OUTPUT_PIN, SUB2_INPUT_PIN),
									AnalogOut( SUB3_OUTPUT_PIN, SUB3_INPUT_PIN) };

/*
 * Read in current sensor output voltage and convert it to mA.
 *
 * @return Current in mA. 
 */
int read_current()
{
	analogReference(DEFAULT);
	analogRead(CURRENT_SENS_PIN);
	int value = analogRead(CURRENT_SENS_PIN);
	value -= current_offset;	// Zero shift
	value *= current_cal;	// Convert to mA.
	analogReference(INTERNAL);
	analogRead(SUB0_INPUT_PIN);
	return value;
}

/*
 * Read in power voltage and convert to V.
 *
 * @return Power supply voltage in V. 
 */
float read_voltage()
{
	// Using the internal reference here.
	float value = analogRead(VOLTAGE_SENS_PIN);
	value *= voltage_cal;	// Convert to V.
	return value;
}

/**
 * Load stored values from EEPROM to system
 */
void load_defaults()
{
	uint8_t charvalue = 0;
	EEPROM.get(EEPROM_ADDRESS_CHECK, charvalue);
	if (charvalue == DEFAULT_CHECK)
	{
		eeprom_get_id(EEPROM_ADDRESS_ID);
		EEPROM.get(EEPROM_ADDRESS_CURRENT_OFFSET, current_offset);
		EEPROM.get(EEPROM_ADDRESS_CURRENT_CAL, current_cal);
		EEPROM.get(EEPROM_ADDRESS_VOLTAGE_CAL, voltage_cal);

		for (uint8_t i=0; i<MAX_SUBDEVICES; i++)
		{
			int offset = EEPROM_PERIOD_SD*i;

			float value = 0.0;
			EEPROM.get(EEPROM_ADDRESS_SD_CAL + offset, value);
			subdevices[i].calibration = value;

			EEPROM.get(EEPROM_ADDRESS_SD_P + offset, value);
			subdevices[i].set_P(value);
			EEPROM.get(EEPROM_ADDRESS_SD_I + offset, value);
			subdevices[i].set_I(value);
			EEPROM.get(EEPROM_ADDRESS_SD_D + offset, value);
			subdevices[i].set_D(value);
		}
	}
	else
	{
		factory_reset();
	}
}

/**
 * Store values from system to EEPROM as defaults
 */
void store_defaults()
{
	eeprom_put_id(EEPROM_ADDRESS_ID);
	EEPROM.put(EEPROM_ADDRESS_CURRENT_OFFSET, current_offset);
	EEPROM.put(EEPROM_ADDRESS_CURRENT_CAL, current_cal);
	EEPROM.put(EEPROM_ADDRESS_VOLTAGE_CAL, voltage_cal);

	for (uint8_t i=0; i<MAX_SUBDEVICES; i++)
	{
		int offset = EEPROM_PERIOD_SD*i;

		float value = subdevices[i].calibration;
		EEPROM.put(EEPROM_ADDRESS_SD_CAL + offset, value);

		value = subdevices[i].get_P();
		EEPROM.put(EEPROM_ADDRESS_SD_P + offset, value);
		value = subdevices[i].get_I();
		EEPROM.put(EEPROM_ADDRESS_SD_I + offset, value);
		value = subdevices[i].get_D();
		EEPROM.put(EEPROM_ADDRESS_SD_D + offset, value);
	}
}

/**
 * Reset stored values to original defaults
 */
void factory_reset()
{
	uint8_t charvalue = DEFAULT_CHECK;
	EEPROM.put(EEPROM_ADDRESS_CHECK, charvalue);

	init_id(DEFAULT_ID);
	current_offset = DEFAULT_CURRENT_OFFSET;
	current_cal = DEFAULT_CURRENT_CAL;
	voltage_cal = DEFAULT_VOLTAGE_CAL;
	for (uint8_t i=0; i<MAX_SUBDEVICES; i++)
	{
		subdevices[i].calibration = DEFAULT_CALIBRATION;
		subdevices[i].set_P(DEFAULT_SD_P);
		subdevices[i].set_I(DEFAULT_SD_I);
		subdevices[i].set_D(DEFAULT_SD_D);
	}
	
	store_defaults();
}

/**
 * Convert variable number to sensor_id and sensor_command.
 *
 * @param variable_number Takes the variable number as input and stores the sensor variable number as output.
 * @param sensor_id Outputs the number of the sensor.
 */
void parse_array_command(int &variable_number, int &sensor_id)
{
	variable_number -= SERIAL_ARRAY_BEGIN;
	sensor_id = variable_number / SERIAL_ARRAY_PERIOD;
	variable_number = variable_number % SERIAL_ARRAY_PERIOD;
}

/**
 * Checks serial line for commands and executes them.
 */
void parse_serial()
{
	while (Serial.available() > 0)
	{
		char command = Serial.read();
		int og_variable_number = 0;
		int variable_number = 0;
		int sub_id = 0;

		if (command == 'R')
		{
			// Read variable
			variable_number = Serial.parseInt();
			og_variable_number = variable_number;

			if (variable_number >= SERIAL_ARRAY_BEGIN)
			{
				// Read subdevice variable
				parse_array_command(variable_number, sub_id);
				if (sub_id < MAX_SUBDEVICES)
				{
					switch (variable_number)
					{
						case 0:
							// Read light intensity setvalue
							Serial.println(subdevices[sub_id].get_setpoint());
							break;
						case 1:
							// Read calibration value
							Serial.println(subdevices[sub_id].calibration);
							break;
						case 2:
							// Read PID Proportional constant
							Serial.println(subdevices[sub_id].get_P());
							break;
						case 3:
							// Read PID Integral constant
							Serial.println(subdevices[sub_id].get_I());
							break;
						case 4:
							// Read PID Derivative constant
							Serial.println(subdevices[sub_id].get_D());
							break;
						default:
							// Syntax error
							error_type = ERROR_SERIAL;
							error_value = og_variable_number;
							break;
					}
				}
				else
				{
					// Sensor index out of range
					error_type = ERROR_SERIAL;
					error_value = og_variable_number;
				}
			}
			else
			{
				// Read device-wide variable
				switch (variable_number)
				{
					case 1:
						// Device identifier
						Serial.println(device_id);
						break;
					case 2:
						// Number of subdevices
						Serial.println(MAX_SUBDEVICES);
						break;
					case 3 :
						// Power enable
						Serial.println(power_enable?1:0);	
						break;
					case 4:
						// Power current
						Serial.println(read_current());
						break;
					case 5:
						// Current measurement offset
						Serial.println(current_offset);
						break;
					case 6:
						// Current measurement conversion
						Serial.println(current_cal);
						break;
					case 7:
						// Power voltage
						Serial.println(read_voltage());
            break;
					case 8:
						// Voltage measurement conversion
						Serial.println(voltage_cal);
						break;
					case 9:
						// Error register
						Serial.print(error_type);
						Serial.print('-');
						Serial.println(error_value);
						error_type = ERROR_NO_ERROR;
						error_value = 0;
						break;
					default:
						// Syntax error
						error_type = ERROR_SERIAL;
						error_value = og_variable_number;
						break;
				}
			}
			if (AnalogOut::error != ANALOGOUT_ERROR_OK)
			{
				error_type = ERROR_ANALOGOUT;
				error_value = AnalogOut::error;
				AnalogOut::error = ANALOGOUT_ERROR_OK;
			}
		}
		else if (command == 'S')
		{
			// Write variable
			variable_number = Serial.parseInt();
			og_variable_number = variable_number;
			Serial.read();
			int variable_value_int = 0;
			float variable_value_float = 0;

			if (variable_number >= SERIAL_ARRAY_BEGIN)
			{
				// Write subdevice variable
				parse_array_command(variable_number, sub_id);
				if (sub_id < MAX_SUBDEVICES)
				{
					switch (variable_number)
					{
						case 0:
							// Write light intensity
							variable_value_int = Serial.parseInt();
							if (variable_value_int <= 100 && variable_value_int >= 0)
							{
								subdevices[sub_id].set_setpoint(variable_value_int);
							}
							else
							{
								error_type = ERROR_SERIAL;
								error_value = og_variable_number;
							}
							break;
						case 1:
							// Write calibration value
							variable_value_float = Serial.parseFloat();
							subdevices[sub_id].calibration = variable_value_float;
							break;
						case 2:
							// Write PID Proportional constant
							variable_value_float = Serial.parseFloat();
							subdevices[sub_id].set_P(variable_value_float);
							break;
						case 3:
							// Write PID Integral constant
							variable_value_float = Serial.parseFloat();
							subdevices[sub_id].set_I(variable_value_float);
							break;
						case 4:
							// Write PID Derivative constant
							variable_value_float = Serial.parseFloat();
							subdevices[sub_id].set_D(variable_value_float);
							break;
						default:
							// Syntax error
							error_type = ERROR_SERIAL;
							error_value = og_variable_number;
							break;
					}
				}
				else
				{
					// Sensor index out of range
					error_type = ERROR_SERIAL;
					error_value = og_variable_number;
				}
			}
			else
			{
				// Write device-wide variable
				switch (variable_number)
				{
					case 1:
						// Device identifier
						serial_read_id();
						break;
					case 3:
						// Enable power
						variable_value_int = Serial.parseInt();
						power_enable = variable_value_int == 1;
						digitalWrite(SSRELAY_PIN, power_enable?HIGH:LOW);
						break;
					case 5:
						// Current measurement offset
						current_offset = Serial.parseInt();
						break;
					case 6:
						// Current measurement conversion
						current_cal = Serial.parseInt();
						break;
					case 8:
						// Voltage measurement conversion
						voltage_cal = Serial.parseFloat();
						break;
					case 10:
						// Save defaults
						store_defaults();
						store_defaults();
						break;
					case 11:
						// Factory reset
						factory_reset();
						break;
					default:
						// Syntax error
						error_type = ERROR_SERIAL;
						error_value = og_variable_number;
						break;
				}
			}
			if (AnalogOut::error != ANALOGOUT_ERROR_OK)
			{
				error_type = ERROR_ANALOGOUT;
				error_value = AnalogOut::error;
				AnalogOut::error = ANALOGOUT_ERROR_OK;
			}
		}
	}
}

void setup()
{
	// Load stored values from EEPROM
	load_defaults();

	// Initialize general pins
	pinMode(SSRELAY_PIN, OUTPUT);
	digitalWrite(SSRELAY_PIN, power_enable?HIGH:LOW);
	pinMode(CURRENT_SENS_PIN, INPUT);
	
	// Initialize sensors
	analogReference(INTERNAL);
	analogRead(SUB0_INPUT_PIN);	// FIrst value read after changing reference is wrong.
	for (uint8_t i=0; i<MAX_SUBDEVICES; i++)
	{
		subdevices[i].init();
	}

	// Setup timer 1
	// PWM 9 and 10 cannot be used.
	TCCR1A = 0;            // Init Timer1A
	TCCR1B = 0;            // Init Timer1B
	TCCR1B |= B00000011;   // Prescaler = 1:64
	OCR1A = TIMER_COUNTER; // Timer Compare1A Register (COMPA)
	TIMSK1 |= B00000010;   // Enable Timer COMPA Interrupt

	// Initialize Serial interface
	Serial.begin(9600);
}

void loop()
{
	while (true)
	{
		parse_serial();
	}
}

/**
 * Interrupt service routine for TIMER1 COMPA event.
 * Set to run every 100mS, updates PIDs.
 */
ISR(TIMER1_COMPA_vect)
{
	OCR1A += TIMER_COUNTER;
	for (uint8_t i=0; i<MAX_SUBDEVICES; i++)
	{
		subdevices[i].update();
	}
}

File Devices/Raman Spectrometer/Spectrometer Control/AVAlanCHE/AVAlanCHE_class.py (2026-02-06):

"""
Author: Elia Savino
github: github.com/EliaSavino

Happy Hacking!

Descr:
This is the script on server side that controls the spectrometer. is built on the avaspec.py dll from Avantes. Documentation
for which can be found on the group drive under: General/13.instrumentsData/AvantesDLL

The main idea is to have a class that the server can instantiate, then the class has modules for setup, firing, dark saving,
and plotting. The server can then call these modules as needed.

Heads up This only works if
1) the spectrometer is connected to the rasberry pi via USB
2) the raspberry pi has the avantes dll installed (otherwise the raspberry has no way of telling the spectrometer what to do)
3) the gods have decided that you are worthy of using the spectrometer

"""

import sys
import os

sys.path.append(os.getcwd())
sys.path.append(os.path.join(os.getcwd(), "AVAlanCHE"))

import avaspec as ava
import RPi.GPIO as GPIO
import numpy as np
from datetime import datetime
import pandas as pd
import threading
import time
from queue import Queue
from utils import setup_logger


def error_handler(jerry):
    def wrapper(*args, **kwargs):
        try:
            return jerry(*args, **kwargs)
        except Exception as e:
            print(f"Something went wrong: {e}")

    return wrapper


def wlen_to_shift(wlen: np.array, wlen0=785.0):
    """converts wavelength in nm to raman shift (cm^-1)
    :param wlen: wavelength in nm (np.array)
    :param wlen0: laser wavelength in nm
    :return: raman shift in cm^-1 (np.array)
    """
    return 1e7 * (1 / wlen0 - 1 / wlen)


class AVAlanCHE:
    def __init__(self):
        """
        Initializes the AVAlanCHE class, the primary interface for controlling the Raman spectrometer.

        Upon instantiation, this class initializes the spectrometer device, sets up the default measurement
        configuration, and prepares the system for taking measurements. It establishes logging, initializes
        the spectrometer library, sets up device and laser control, and defines default parameters for
        spectrometer operations.

        Attributes:
            logger (logging.Logger): Logger for the class, used to log informational messages and errors.
            ready_to_measure (bool): Flag indicating whether the spectrometer is ready to take measurements.
            default_parameters (dict): Dictionary containing default spectrometer operation parameters, such as
                                       integration time, number of averages, measurement delay, and save settings.
            current_parameters (dict): A copy of `default_parameters` that can be modified based on runtime
                                       configurations.
            stop_requested (threading.Event): An event flag used primarily in GUI applications to signal when
                                               measurement processes should be halted.

        Operations:
            - Initializes the spectrometer and sets it ready for measurements.
            - Sets up a default measurement configuration with predefined parameters.
            - Prepares the laser control for the spectrometer.
            - Establishes a default save path for data collected during spectrometer operations.

        Note:
            This class is designed to be simple and straightforward for interfacing with the Raman spectrometer
            without sacrificing performance. It encapsulates the necessary setup, configuration, and control
            functionalities required to operate the spectrometer effectively.
        """

        self.log = setup_logger(self.__class__.__name__, "AVAlanCHE.log")
        self.log.info("Initializing AVAlanCHE class...")

        try:
            # Initialize the spectrometer library
            self.log.debug("Initializing AvaSpec library...")
            ava.initialise()
            self.log.info("AvaSpec library initialized successfully.")
        except Exception as e:
            self.log.exception("Error initializing AvaSpec library: %s", e)
            raise

        self.ready_to_measure = False
        self.log.info("Set ready_to_measure to False.")

        try:
            # Set up the device
            self.log.debug("Setting up the spectrometer device...")
            self.setup_device()
            self.log.info("Spectrometer device setup successfully.")
        except Exception as e:
            self.log.exception("Error during device setup: %s", e)
            raise

        try:
            # Initiate measurement configuration
            self.log.debug("Initializing measurement configuration...")
            self.measuring = True
            self.init_measconfig()
            self.log.info("Measurement configuration initialized.")
        except Exception as e:
            self.log.exception("Error initializing measurement configuration: %s", e)
            raise

        # Set default parameters
        self.default_parameters = {
            "integration_time": 1000.0,
            "n_averages": 1,
            "n_scans": 1,
            "delay (ms)": 1000.0,
            "correct_dark": True,
            "dynamic_correct_dark": False,
            "save_as": "single",
            "save_path": self._default_save_path(),
            "safety_threshold": 10000,
            "save_moniker": None,
            "save": True,
        }
        self.log.debug(f"Default parameters set: {self.default_parameters}")

        self.current_parameters = self.default_parameters.copy()
        self.log.debug(
            "Current parameters initialized as a copy of default parameters."
        )

        try:
            # Setup laser control
            self.log.debug("Setting up laser control...")
            self.setup_laser_control()
            self.log.info("Laser control setup successfully.")
        except Exception as e:
            self.log.exception("Error during laser control setup: %s", e)
            raise

        # Calculate spectrometer polling time
        self.spec_polltime = (
            (
                self.current_parameters["integration_time"]
                * self.current_parameters["n_averages"]
            )
            + self.current_parameters["delay (ms)"]
        ) / 1000.0
        self.log.debug(
            f"Spectrometer polling time calculated: {self.spec_polltime} seconds"
        )

        # Initialize stop event for GUI apps
        self.stop_requested = threading.Event()
        self.log.info("Stop_requested event initialized.")

        self.log.info("AVAlanCHE class initialized successfully.")

    def _default_save_path(self):
        """
        Generates the default save path for storing Raman spectra data.
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

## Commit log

2026-03-24 improved pump reliabilty
2026-04-20 Add opus reports 05, 07, 09: ML loop, analytics, Arduino protocol
    https://claude.ai/code/session_01QPqBHE4CDRqivqAd3RbJB7
2026-04-20 Add opus report 03: unit-task to wire trace
    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
2026-04-20 Add opus reports 06 and 10: sample prep and safety/errors
    Report 06 was written directly after two agent timeouts on that topic.
    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
